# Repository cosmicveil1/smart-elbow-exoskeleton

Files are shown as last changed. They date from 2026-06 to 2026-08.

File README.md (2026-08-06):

# 🦾 Smart Elbow Exoskeleton Rehabilitation Platform

**"An intelligent, clinical-grade IoT telemetry platform that analyzes kinematic telemetry to classify movement quality, detect abnormal rehabilitation sessions, and support adaptive therapy decisions."**

Built for researchers, clinicians, and engineers to collaborate on data-driven patient recovery, this project combines low-latency IoT hardware control with a robust React-based clinical dashboard and an advanced Machine Learning data pipeline.

---

## 1. High-Level Project Architecture

```mermaid
graph TD
    subgraph Dashboard [React.js SPA Dashboards]
        Doc[🩺 Doctor Portal<br/>Checklist Tracking]
        Pat[🤕 Patient Portal<br/>Real-time SVG Arm]
        Eng[⚙️ Engineer Portal<br/>Diagnostics & Logs]
    end
    
    subgraph API [FastAPI REST Server]
        Endpoints[API Endpoints<br/>JWT Auth & Bcrypt]
        DB[(PostgreSQL Database<br/>elbow_db)]
        ORM[SQLAlchemy ORM]
        
        Endpoints <--> ORM
        ORM <--> DB
    end
    
    subgraph Collector [Python Serial Bridge]
        Script[pySerial Bridge Script<br/>elbow_encoder.py]
    end
    
    subgraph Hardware [Exoskeleton Hardware]
        Arduino[Arduino Uno MCU<br/>+ Rotary Encoder 8192 ticks/rev<br/>+ L298N Motor Driver]
    end
    
    Doc -->|Axios REST Requests<br/>& Hardware Commands| Endpoints
    Pat -->|Polls Telemetry<br/>& Hardware Commands| Endpoints
    Eng -->|Query Session Logs| Endpoints
    
    Arduino -->|USB Serial COM6 @ 115200<br/>Telemetry Stream| Script
    Script -->|USB Serial<br/>Hardware Commands| Arduino
    Script -->|HTTP POST Telemetry| Endpoints
    Endpoints -->|HTTP GET Pending Commands| Script
```

---

## 2. End-to-End Two-Way Data Flow

The platform pipeline is divided into the Telemetry (Upload) and Command (Download) flows:

### Telemetry Flow (Hardware -> Dashboard)
1. **Generation:** The patient moves their elbow. The high-resolution rotary encoder generates ticks (8192 per revolution).
2. **Microcontroller Ingestion:** The Arduino converts raw ticks into angle degrees and rotation direction, printing it to the serial line.
3. **Data Collector Ingestion:** The Python script [elbow_encoder.py](collector/elbow_encoder.py) reads this stream via `pySerial` at 115200 baud, logs raw backup data to local CSV files, and sends an HTTP POST payload to the backend's `/data/` endpoint. This script implements an asynchronous, multi-threaded bi-directional IoT communication bridge to handle high-frequency telemetry without dropping packets.
4. **API & DB Save:** The FastAPI backend receives the JSON payload and saves it to the PostgreSQL `elbow_data` table.
5. **Real-time Display:** Both Doctor and Patient React Dashboards display the data using Live Recharts Line Graphs and dynamic SVG Skeletal Arm animations.

### Hardware Control Flow (Dashboard -> Hardware)
1. **Doctor/Patient Command:** A user clicks "Set Target Angle", "Zero Sensor", or "Emergency Stop" on the React Dashboard.
2. **PostgreSQL Queue:** FastAPI saves the command into the `commands` SQL table with a status of `pending`.
3. **Python Bridge Polling:** A background thread in `elbow_encoder.py` polls `GET /commands/pending` every 1 second.
4. **Serial Execution:** The Python script downloads the pending command, marks it as `executed` via `PUT /commands/{id}/execute`, and translates it into a byte string (e.g., `t90.0\n`, `s\n`, `c\n`) sent down the USB cable to the Arduino.
5. **Hardware Response:** The Arduino parses the byte string and engages the L298N motor driver using dynamic macro-PWM logic to reach the target angle.

---

## 3. Data Engineering & ML Telemetry Pipeline

Unlike raw IoT projects, this platform is designed specifically to generate high-variance, clinically relevant Machine Learning datasets for anomaly detection and physical therapy scoring.

### Telemetry Schema
The Python ingestion script (`elbow_encoder.py`) parses the raw serial string and writes structured time-series data directly to local CSVs and PostgreSQL:
`id, session_name, timestamp, target_angle, current_angle, error, motor_status`

> **Note:** The `motor_status` column captures the precise Macro-PWM pulse timing of the motor (ON vs Coast vs Stopped). This serves as a highly predictive feature for mechanical stalling, separating intentional rest from hardware failure.

### Data Collection Strategy
To prevent model overfitting, data is collected across distinct, isolated sessions covering multiple operational classes:
- **Normal Dynamics:** Short/long movements, stepping, and holding.
- **Simulated Anomalies:** 
  - **Frozen Joint / Mechanical Jam:** Motor pulses actively, but encoder remains flat.
  - **Patient Resistance:** Motor pulses actively, but movement is heavily constrained.
  - **Emergency Stops:** Sudden velocity drops triggered via software interrupt.

### Feature Extraction Pipeline & Tooling
To prepare this data for training, I developed custom Python tooling (`crop.py`, `split_session.py`, `export_ml_data.py`) to automate the cropping, splitting, and normalization of time-series sessions. Raw time-series rows are converted into robust rolling windows to extract physics-based features, providing the ML models with true mechanical context:
- `Mean Error`, `Max Error`, `Velocity`, `Acceleration`, `Error Variance`, `Overshoot`, `Settling Time`

---

## 4. Machine Learning Roadmap (Future Work)

**Status:** *During my internship, I successfully built the end-to-end IoT telemetry platform, React dashboard, and full data pipeline. We have successfully collected and structured the high-variance datasets required for ML. The following 4-stage ML pipeline is planned as my next phase of work.*

The platform's data strategy is designed to support a 4-Stage Machine Learning pipeline that will transform our raw kinematics dataset into adaptive therapy recommendations:

* **Stage 1: Movement Classification (RandomForest / XGBoost)**
  - Classify the current movement type (e.g., Short Step, Long Swing, Hold, Jam, Resistance).
* **Stage 2: Anomaly Detection (Isolation Forest)**
  - Train exclusively on normal telemetry to mathematically isolate and flag dangerous deviations (e.g., motor jamming or sudden patient resistance) acting as a proactive, sub-millisecond safety layer.
* **Stage 3: Movement Quality Scoring (Regression)**
  - Grade the patient's exercise execution on a 0-100 scale based on smoothness, overshoot, and velocity profiles.
* **Stage 4: Adaptive Therapy Recommendation Engine**
  - Use the Quality Score to prescribe the next clinical action (e.g., "Increase Range of Motion", "Maintain", or "Decrease Difficulty").

---

## 5. Explaining Key Files by Folder

### 📂 Backend (FastAPI Server)
* **[main.py](backend/main.py):** The API entry point. Initializes database tables, sets up CORS middleware, and registers routers.
* **[database.py](backend/database.py):** Contains the SQLAlchemy configuration and PostgreSQL connection.
* **models directory:** Defines database tables (Users, Exercises, Prescriptions, Sessions, Telemetry).
* **routers directory:** Defines API endpoints for authentication, commands, and clinical data.
* **services directory:** Handles core logic (e.g., bcrypt password hashing and JWT token generation).

### 📂 Ingestion Collector (Python IoT Script)
* **[elbow_encoder.py](collector/elbow_encoder.py):**
  - Connects to the Arduino via `pySerial`.
  - Runs an infinite loop reading the port, logging raw CSV data, and pushing structured data to the backend.

### 📂 Frontend (React TypeScript)
* **[AuthContext.tsx](frontend/src/context/AuthContext.tsx):** Manages global authentication state and role-based access control.
* **[DoctorDashboard.tsx](frontend/src/pages/Doctor/DoctorDashboard.tsx):** Fetches patients and their prescriptions, allowing doctors to create new routines.
* **[PatientDashboard.tsx](frontend/src/pages/Patient/PatientDashboard.tsx):** Engineered a low-latency, dynamic SVG joint visualizer that uses real-time trigonometry to render the patient's arm position live from the hardware feed across multiple camera angles.

### 📂 Firmware (Arduino Control System)
* **[ElbowController.ino](firmware/ElbowController/ElbowController.ino):** The embedded C++ firmware for the Arduino. Implements macroscopic PWM control, a deadband for motor stalling prevention, and streams high-frequency 100Hz telemetry.

### 📂 Mechanical CAD
* **[cad files/](cad%20files/):** Contains the SolidWorks (`.SLDPRT`, `.SLDASM`) models for the 3D-printed exoskeleton components. *Note: We iteratively isolated the elbow joint from the initial full upper-limb suit to create a highly accurate, focused MVP for data collection.*

---

## 6. Quick Start

### 1. Install Dependencies
```bash
# Python dependencies
pip install fastapi uvicorn sqlalchemy psycopg2 requests pyserial python-dotenv PyJWT bcrypt pandas plotly streamlit

# React frontend dependencies
cd frontend
npm install
```

### 2. Seed Database
Reset your PostgreSQL tables and seed default users, templates, and prescriptions:
```bash
venv\Scripts\python.exe -m backend.seed
```

### 3. Start the Platform
* **FastAPI Backend:** `venv\Scripts\python.exe -m uvicorn backend.main:app --port 8001`
* **React Frontend:** `cd frontend && npm start`

---

## 7. Dashboard Roles & Logins

| Role | Username | Password | Key Features |
| :--- | :--- | :--- | :--- |
| **Doctor** | `doctor` | `password` | Searchable patient list, clinical notes, exercise prescription dropdown, exercise template creator. |
| **Patient** | `patient` | `password` | Prescribed routines, target metrics, interactive SVG arm joint simulator, dual-mode selector. |
| **Engineer** | `engineer` | `password` | Hardware connection stats, database logs list, raw telemetry diagnostics table. |

---

## 8. Exoskeleton Wiring & Serial Protocol

### Hardware Setup
* **Rotary Encoder (8192 ticks/revolution):** Phase A $\rightarrow$ D2 (Interrupt), Phase B $\rightarrow$ D3
* **Motor Driver (L298N):** ENA/ENB $\rightarrow$ D5, D6 (PWM), IN1-IN4 $\rightarrow$ D8-11
* **Arduino Uno:** Streams serial data over USB (identified on `COM6`).

### Serial Protocol (Two-Way)
* **Arduino $\rightarrow$ Python Bridge (100 Hz Telemetry):** `Target: 90.0 | Current: 45.0 | Error: 45.0 | ⚡ ON (Pulse)`
* **Python Bridge $\rightarrow$ Arduino (Commands):** `t90.0\n` (Set Target), `s\n` (Stop), `c\n` (Calibrate)

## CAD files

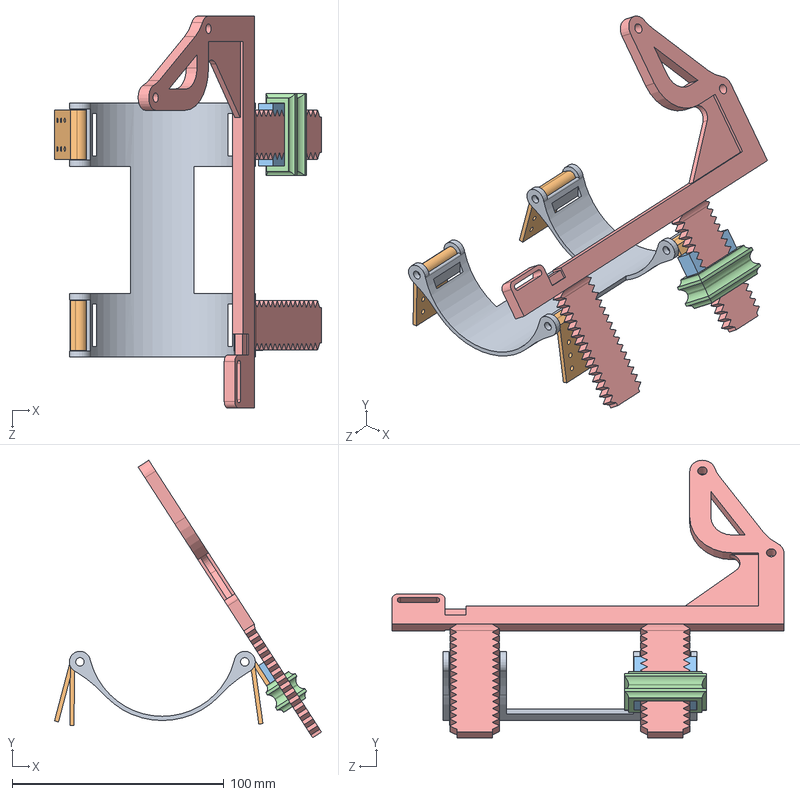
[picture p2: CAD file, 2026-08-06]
cad files/EXO_upper_Assembly.SLDASM
126.0 x 131.0 x 185.0 mm
Upper_arm_base
Hinge_adjust x 4
Linear_adjust
Adjustment_lock_linear
Elbow_UArm_V2

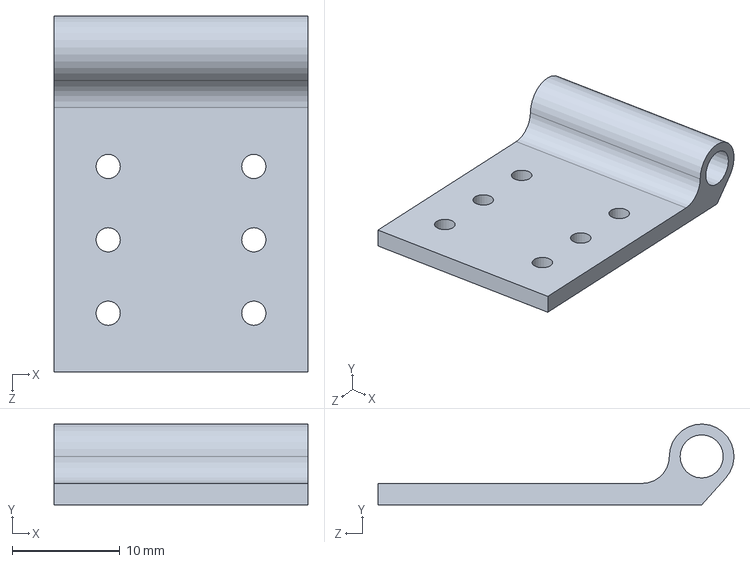
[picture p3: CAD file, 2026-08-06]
cad files/Hinge_adjust.SLDPRT
23.5 x 7.50 x 33.0 mm

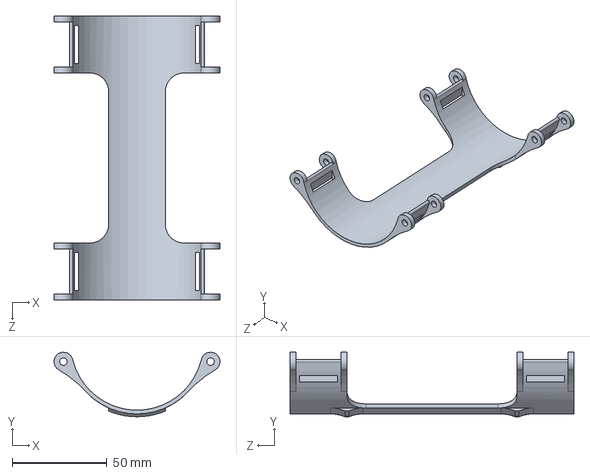
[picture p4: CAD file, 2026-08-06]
cad files/Lower_arm_base.SLDPRT
87.8 x 34.2 x 150.0 mm

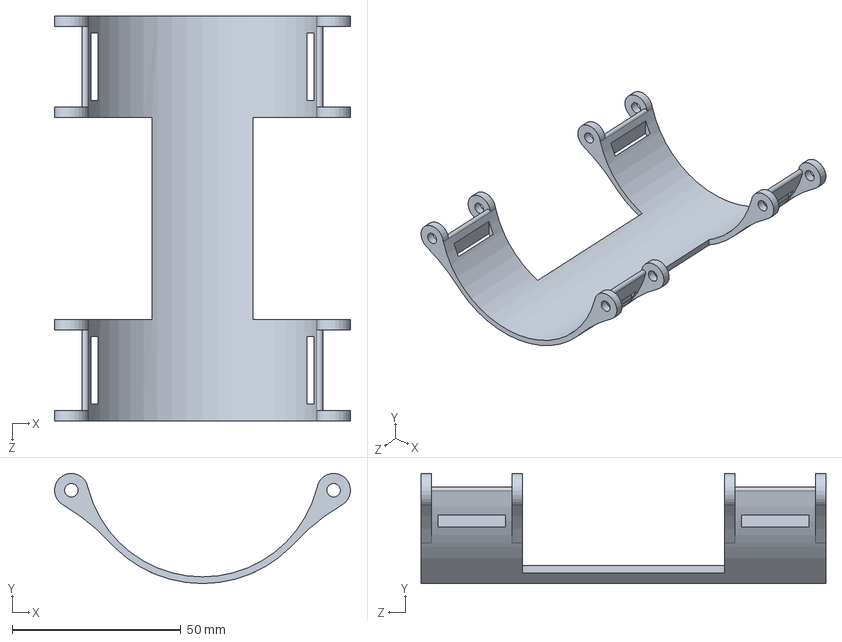
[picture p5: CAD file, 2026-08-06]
cad files/Upper_arm_base.SLDPRT
87.8 x 32.7 x 120.0 mm

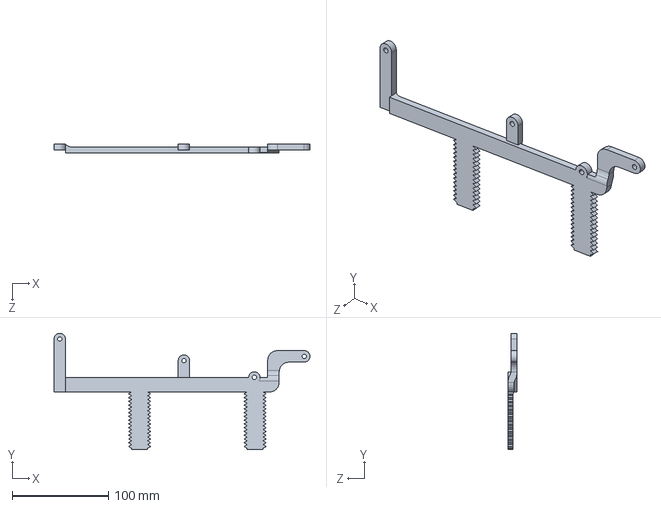
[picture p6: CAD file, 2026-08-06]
cad files/Inner_Elbow_LArm_V2.SLDPRT
266.0 x 121.0 x 9.00 mm

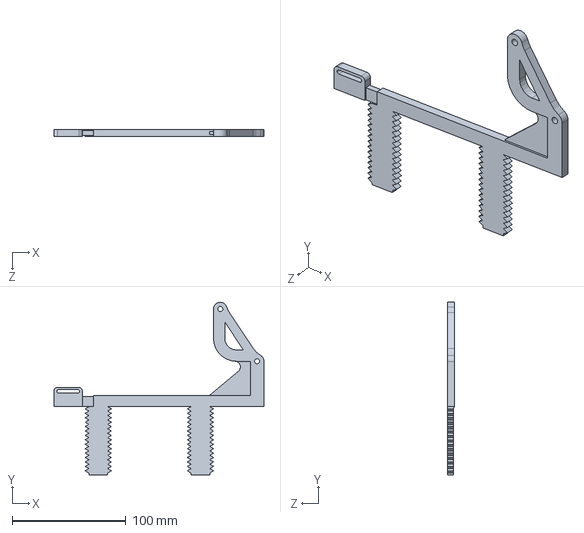
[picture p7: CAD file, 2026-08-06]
cad files/Inner_Elbow_UArm_V2.SLDPRT
185.0 x 152.0 x 6.00 mm

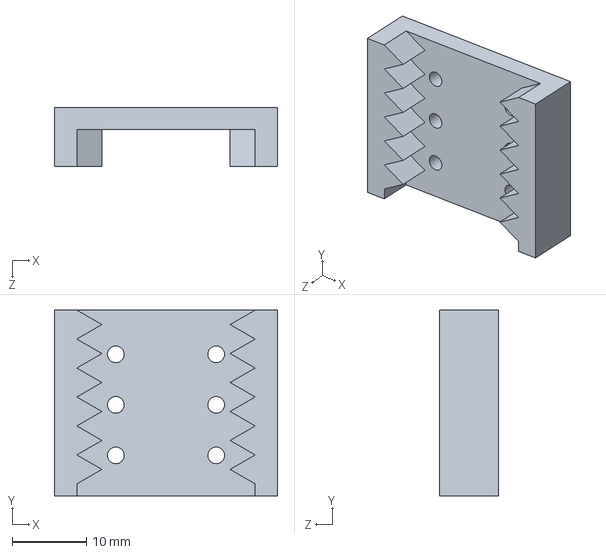
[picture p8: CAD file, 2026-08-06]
cad files/Linear_adjust.SLDPRT
30.0 x 25.0 x 8.00 mm

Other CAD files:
cad files/Elbow_LArm_V2.SLDPRT
cad files/Elbow_UArm_V2.SLDPRT

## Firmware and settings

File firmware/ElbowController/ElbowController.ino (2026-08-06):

// ---------------- MOTOR PINS ----------------
const int ENA = 5;
const int IN1 = 8;
const int IN2 = 9;

const int ENB = 6;
const int IN3 = 10;
const int IN4 = 11;

// ---------------- ENCODER PINS ----------------
#define ENC_A 2
#define ENC_B 3

int PPR = 2048; // Total pulses per revolution
volatile long encoderCount = 0;

// ---------------- CONTROL VARIABLES ----------------
float target_angle = 0.0;
float current_angle = 0.0;
bool is_moving = false;    

// --- TEACHER'S MACROSCOPIC PWM VARIABLES ---
unsigned long pulseTimer = 0;
bool motorPulseActive = false; // Tracks if we are currently in the ON window or OFF window
float ton_duration = 0.0;      // Active ON time in seconds
float toff_duration = 0.0;     // Active OFF time in seconds

unsigned long lastPrintTime = 0;
const unsigned long printInterval = 10; // Print every 10ms (100Hz) to match Python backend

// Arduino R4 Minima fix variable
int last_speed = -1;

void setup() {
  pinMode(ENA, OUTPUT);
  pinMode(IN1, OUTPUT);
  pinMode(IN2, OUTPUT);
  pinMode(ENB, OUTPUT);
  pinMode(IN3, OUTPUT);
  pinMode(IN4, OUTPUT);

  pinMode(ENC_A, INPUT_PULLUP);
  pinMode(ENC_B, INPUT_PULLUP);

  attachInterrupt(digitalPinToInterrupt(ENC_A), readEncoder, RISING);

  Serial.begin(115200); 
}

void loop() {
  unsigned long currentTime = millis();

  // -------- 1. SERIAL COMMAND PARSING --------
  if (Serial.available() > 0) {
    char cmd = Serial.read();
    if (cmd == 't') {
      target_angle = Serial.parseFloat();
    } else if (cmd == 's') {
      target_angle = current_angle; // Stop
    } else if (cmd == 'c') {
      encoderCount = 0;
      target_angle = 0.0;
    }
  }

  // -------- 2. ANGLE CALCULATION --------
  current_angle = (encoderCount * 360.0) / PPR;
  float error = target_angle - current_angle;
  float abs_error = abs(error);

  // -------- 3. MACRO-PWM MOTOR CONTROL --------
  if (abs_error > 5.0) {
    ton_duration = 0.25;    // 0.25 seconds ON (Medium steps)
    toff_duration = 0.1;    // 0.1 seconds OFF
    is_moving = true;
  } 
  else if (abs_error > 0.5 && abs_error <= 5.0) {
    ton_duration = 0.025;   // 0.025 seconds ON (Tiny micro-taps for precision!)
    toff_duration = 0.1;    // 0.1 seconds OFF
    is_moving = true;
  }
  else {
    // 2 > |error| > 1°  -->  Δton = 0
    ton_duration = 0.0;    
    toff_duration = 0.0;
  }

  // --- PULSE STATE MACHINE HANDLING ---
  if (ton_duration == 0.0) {
    stopMotors();
    is_moving = false; 
    motorPulseActive = false;
  } 
  else {
    // Determine if we should be timing the ON window or the OFF window
    unsigned long currentInterval = (motorPulseActive) ? (ton_duration * 1000) : (toff_duration * 1000);

    // Check if current time window has elapsed
    if (currentTime - pulseTimer >= currentInterval) {
      pulseTimer = currentTime; // Reset timer for the next phase
      motorPulseActive = !motorPulseActive; // Flip the switch (ON -> OFF or OFF -> ON)
    }

    // Execute physical power commands
    if (motorPulseActive) {
      applyDirection(error); // Slam the gas pedal! (255 PWM)
    } else {
      stopMotors();          // Take foot off the gas to coast!
    }
  }

  // -------- 4. TELEMETRY OUTPUT --------
  if (currentTime - lastPrintTime >= printInterval) {
    printAngleData(current_angle, error);
    lastPrintTime = currentTime;
  }
}

// ---------------- HELPER FUNCTIONS ----------------

void applyDirection(float error) {
  // 🔄 SWAPPED POLARITY to fix your Forward/Backward issue!
  if (error > 0) {
    // Forward / Flexion (Positive Target)
    digitalWrite(IN1, LOW);
    digitalWrite(IN2, HIGH);
    digitalWrite(IN3, LOW);
    digitalWrite(IN4, HIGH);
  }
  else {
    // Backward / Extension (Negative Target)
    digitalWrite(IN1, HIGH);
    digitalWrite(IN2, LOW);
    digitalWrite(IN3, HIGH);
    digitalWrite(IN4, LOW);
  }
  
  // R4 Minima Fix: Only call analogWrite once when the pulse turns ON
  if (last_speed != 255) {
    analogWrite(ENA, 255);
    analogWrite(ENB, 255);
    last_speed = 255;
  }
}

void stopMotors() {
  digitalWrite(IN1, LOW);
  digitalWrite(IN2, LOW);
  digitalWrite(IN3, LOW);
  digitalWrite(IN4, LOW);

  // R4 Minima Fix: Only call analogWrite once when the pulse turns OFF
  if (last_speed != 0) {
    analogWrite(ENA, 0);
    analogWrite(ENB, 0);
    last_speed = 0; 
  }
}

void printAngleData(float currentAngle, float error) {
  Serial.print("Target: "); Serial.print(target_angle);
  Serial.print(" | Current: "); Serial.print(currentAngle);
  Serial.print(" | Error: "); Serial.print(error);
  if (!is_moving) {
    Serial.println(" | ⚡ OFF (STOPPED)");
  } else {
    Serial.println(motorPulseActive ? " | ⚡ ON (Pulse)" : " | ⚡ OFF (Coast)");
  }
}

// ---------------- ENCODER ISR ----------------
void readEncoder() {
  int b = digitalRead(ENC_B);
  // 🔄 SWAPPED POLARITY to match the reversed motor!
  if (b == HIGH) {
    encoderCount--; 
  } else {
    encoderCount++; 
  }
}

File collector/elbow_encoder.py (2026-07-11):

import os
import serial
import time
import csv
import requests
import threading
from datetime import datetime

# ================== CONFIGURATION ==================
SERIAL_PORT = 'COM6'          
BAUD_RATE = 115200

# FastAPI Backend URLs
BASE_URL = "http://127.0.0.1:8000"
FASTAPI_URL = f"{BASE_URL}/data/"   
FASTAPI_SESSIONS_URL = f"{BASE_URL}/sessions/"
FASTAPI_COMMANDS_URL = f"{BASE_URL}/commands/"

# Create a persistent session for high-speed streaming
session = requests.Session()
# ==================================================

# ================== 🌟 AUTOMATED SESSION SCRIPTING 🌟 ==================
# 1. Ask for Patient ID and Session Name at the start of the test
patient_id = input("👤 Enter Patient ID (e.g., 2 for John Doe): ").strip()
if not patient_id:
    patient_id = "unknown_patient"

session_name = input("📝 Enter Session Name (optional): ").strip()
if not session_name:
    session_name = f"Session_{datetime.now().strftime('%Y-%m-%d_%H-%M-%S')}"

# 2. Get today's date and time strings
today_date = datetime.now().strftime("%Y_%m_%d")
time_str = datetime.now().strftime("%H-%M-%S")

# 3. Create an organized directory path: data/patient_id/
session_dir = os.path.join("data", patient_id)
os.makedirs(session_dir, exist_ok=True)  # Automatically creates folders if they don't exist

# 4. Generate dynamic filenames inside that patient's folder
csv_filename = os.path.join(session_dir, f"session_{today_date}_{time_str}_parsed.csv")
raw_filename = os.path.join(session_dir, f"session_{today_date}_{time_str}_raw.csv")

print(f"📁 Session localized! Saving parsed telemetry to: {csv_filename}")
print(f"📁 Saving raw stream logs to: {raw_filename}")

# 5. Connect to FastAPI backend to register the session
session_id = None
try:
    print(f"📡 Registering session for Patient '{patient_id}' on backend: {FASTAPI_SESSIONS_URL} ...")
    session_payload = {
        "patient_id": patient_id,
        "session_name": session_name,
        "notes": f"Local CSV directory: {session_dir}"
    }
    response = requests.post(FASTAPI_SESSIONS_URL, json=session_payload, timeout=5)
    if response.status_code == 200:
        session_id = response.json().get("id")
        print(f"✅ Session registered successfully! Database Session ID: {session_id}")
    else:
        print(f"❌ Failed to register session: {response.status_code} - {response.text}")
        print("💡 Make sure FastAPI backend is running and the database is configured.")
        raise RuntimeError("Session registration failed.")
except requests.exceptions.ConnectionError:
    print("❌ Cannot connect to backend. Is FastAPI still running on http://127.0.0.1:8001?")
    print("💡 Please start the backend before running the data collector.")
    raise SystemExit(1)
except Exception as e:
    print(f"❌ Error during session creation: {e}")
    raise SystemExit(1)
# =======================================================================

# Open the files globally using your dynamic paths
csv_file = open(csv_filename, 'w', newline='', encoding="utf-8")
raw_file = open(raw_filename, 'w', newline='', encoding="utf-8")

csv_writer = csv.writer(csv_file)
raw_writer = csv.writer(raw_file)

csv_writer.writerow(["Timestamp", "Target_Angle", "Current_Angle", "Error", "Motor_Status"])
raw_writer.writerow(["Timestamp", "Raw_Data"])

print(f"✅ Trying to connect to Arduino on {SERIAL_PORT}...")
print(f"📡 Sending data to FastAPI: {FASTAPI_URL}")

def command_polling_thread(ser_port):
    """Background thread to poll FastAPI for new commands and push them to the Arduino."""
    while True:
        try:
            res = requests.get(f"{FASTAPI_COMMANDS_URL}pending", timeout=3)
            if res.status_code == 200:
                commands = res.json()
                for cmd in commands:
                    cmd_id = cmd["id"]
                    ctype = cmd["command_type"]
                    cval = cmd["value"]

                    if ctype == "TARGET_ANGLE":
                        ser_port.write(f"t{cval}\n".encode('utf-8'))
                        print(f"⚡ [COMMAND QUEUE] Sent Target Angle: {cval}° to Arduino")
                    elif ctype == "STOP":
                        ser_port.write(b"s\n")
                        print(f"🚨 [COMMAND QUEUE] EMERGENCY STOP SENT TO ARDUINO")
                    elif ctype == "ZERO":
                        ser_port.write(b"c\n")
                        print(f"🎯 [COMMAND QUEUE] SENSOR CALIBRATED TO ZERO")
                    
                    # Mark executed
                    requests.put(f"{FASTAPI_COMMANDS_URL}{cmd_id}/execute", timeout=3)
        except Exception as e:
            pass # Silently ignore connection errors during polling to avoid console spam
        time.sleep(1)
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

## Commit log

2026-06-02 Docs: replace ASCII architecture diagram with Mermaid flowchart to avoid alignment issues
2026-07-11 Update README, add ML anomaly detection pipeline, and refine telemetry parsing
    [ml_anomaly.csv, ml_normal_baseline.csv]
2026-08-06 feat: Added original CAD models and restored Arduino firmware
    [EXO_upper_Assembly.SLDASM, Elbow_LArm_V2.SLDPRT, Elbow_UArm_V2.SLDPRT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]
2026-08-06 docs: Documented firmware and CAD directories
